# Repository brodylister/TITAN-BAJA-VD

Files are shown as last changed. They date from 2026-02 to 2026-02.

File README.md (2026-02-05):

## Baja SAE – Titan Racing Baja
Titan Racing Baja SAE is a mechanical engineering club for students to design, build and race a custom off-road vehicle for the annual collegiate competition. Designing and building a car requires us to apply engineering problems to the real world. We gain invaluable skills in design, manufacturing, and project management that prepare us for professional careers. At **CSUF**, our Baja SAE team consists of 14 members, and our goal is to compete in the BAJA SAE Competion that is in Washougal, Washington in May 2026. We are divided into four subteams:

- Chassis / Ergonomics 
- Drivetrain  
- Suspension  
- Vehicle Dynamics / Data Acquisition  

---

## Vehicle Dynamics & Data Acquisition
For the **Vehicle Dynamics / Data Acquisition (VD/DAQ)** subteam, this focuses heavily on the electrical, sensor data, and data analysis work on the car.

We currently run **8 sensors** on the Baja car, all connected to an Arduino based DAQ system to record performance data during testing and competition runs. The system logs:

- Vehicle speed  
- Distance traveled  
- Time  
- Engine RPM  
- Secondary (CVT) RPM  
- Gyroscope data (roll, pitch, yaw)  
- 3-axis acceleration  
- Brake pressure bias  

All sensor data is routed through an **Arduino and SD card reader shield**, allowing each run to be logged directly to an SD card. The recorded data is then processed and analyzed in **MATLAB** to evaluate vehicle performance, CVT behavior, braking balance, and driver inputs.

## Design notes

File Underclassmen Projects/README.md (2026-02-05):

## Underclassmen Projects (Coding)

I have a few underclassmen projects for anyone interested in writing code for **CVT tuning** and the **main DAQ harness** that will be installed on the car. These projects are a great opportunity to gain hands on experience with Arduino based data acquisition and sensor integration.

For coding related work, please reference **version 8 (v8)** of the code located in either the **CVT** or **DAQ** folders. This version should be used as the baseline for development.

If you’re interested, **reach out to Katia on Discord**, and she can answer any questions you may have and help you get started.

---

### CVT DYNO

- [ ] Add code to output **live data** onto a screen  
- [ ] Display outputs for:
  - [ ] Hall effect sensor (Primary RPM)  
  - [ ] Hall effect sensor (Secondary RPM)  
  - [ ] Hall effect sensor (Disk Brake RPM)  

---

### DAQ (On Vehicle)

- [ ] Code the **IMU (MPU-6050)** to record and send its data to the Arduino  
- [ ] Log IMU data onto an SD card using the **SD Card Reader Shield** (so it can be exported to Excel / MATLAB later)  
- [ ] IMU signals to record:
  - [ ] Angular velocity (gyro): **X, Y, Z**
  - [ ] Linear acceleration (accelerometer): **X, Y, Z**

> Note: The MPU-6050 is a 3-axis accelerometer and gyroscope. There are many examples available on GitHub and YouTube that can be used as references.

---

## Underclassmen Projects (Hands On)

For those interested in hands on work, there are opportunities to help test and validate the sensors we are using by connecting them to an Arduino and breadboard while we wait for final parts to be delivered. This is a great way to get familiar with the hardware and basic wiring before full integration.

A future project will involve assisting with **harness assembly and integration** once all components arrive, including helping connect and route the wiring for the CVT dyno and on vehicle DAQ systems. Interested students should reach out to Katia for more information.

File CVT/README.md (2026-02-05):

## CVT Dyno Harness & Tuning Overview

In addition to the vehicle DAQ system, we are developing a **separate electrical harness for the CVT dyno**. This setup is designed specifically for **CVT testing and tuning** in a controlled environment and does not require the same level of durability as the on vehicle harness.

The CVT dyno harness uses an **Arduino Uno with an SD card reader shield** to log data and display real time feedback during testing. The system includes the following components:

- Hall effect sensor – Primary RPM  
- Hall effect sensor – Secondary RPM  
- Hall effect sensor – Disk Brake RPM  
- Push button (test control / reset)  
- LED indicators (system status)  
- Real Time Clock (RTC)  
- Display screen for real time output  

The hall effect sensors allow us to measure **primary, secondary, and wheel RPM**, which are critical for understanding CVT behavior under different load and throttle conditions. Data is logged to an SD card for analysis, while the display provides immediate feedback during testing.

---

## Purpose of CVT Tuning

The purpose of CVT tuning is to optimize the transmission’s performance by ensuring the engine operates within its ideal RPM range throughout acceleration and load changes. By analyzing the relationship between **primary RPM, secondary RPM, and wheel RPM**, we can evaluate:

- Shift behavior and ratio changes  
- Belt slip and engagement consistency  
- Backshift response under load  
- Overall drivetrain efficiency  

This data approach allows us to make informed adjustments to **spring rates, flyweights, and CVT setup** rather than relying solely on trial and error. The CVT dyno harness provides a repeatable testing environment that directly supports on vehicle performance improvements.

---

## To Do List

- [x] Hall effect sensor – Primary RPM  
- [x] Hall effect sensor – Secondary RPM  
- [x] Hall effect sensor – Disk Brake RPM  
- [x] Push button (test control / reset)  
- [x] LED indicators (system status)  
- [x] Real-Time Clock (RTC)  
- [ ] Display screen for real-time output

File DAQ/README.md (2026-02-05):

## System Overview

The DAQ system is responsible for collecting sensor data during testing and competition runs, logging it to an SD card. The on vehicle DAQ system is built around an **Arduino** paired with an **SD card reader shield**. Sensor inputs are recorded during each run and saved to an SD card for later analysis. This data is used to evaluate vehicle performance, driver behavior, and drivetrain response under real off road conditions.

Power for the DAQ system is supplied by the vehicle’s **12V battery**. A **buck converter** is used to step the voltage down from **12V to 5V** for sensors and components that require regulated 5V power, ensuring stable operation and protecting sensitive electronics.

---

## Sensors & Components

### Core DAQ Hardware
- Arduino  
- SD card reader shield  
- Buck converter (12V → 5V)

### Sensors / Inputs
- Brake Pressure Sensor (BPS)  
- Hall effect sensor – Secondary RPM  
- Spark plug RPM pickup – Primary RPM  
- IMU (gyroscope + accelerometer)  
- IR sensor (temperature monitoring)  
- GPS module (position / speed tracking)  
- Real Time Clock (RTC)  
- Push button (test control / marker)  
- LED indicators (system status)

---

## Data Logging & Output

During a run, sensor signals are routed into the Arduino, time stamped using the RTC, and logged to the SD card. Data is then transferred for processing and analysis in **MATLAB**, where it can be used to evaluate:

- Vehicle speed and distance trends  
- Engine and CVT RPM behavior  
- Brake pressure bias and braking consistency  
- Vehicle dynamics (roll, pitch, yaw, and acceleration)  
- Thermal behavior from IR sensor readings  
- GPS-based track mapping and run comparison  

---

## Live Transmission

In addition to SD logging, the DAQ system supports **live transmission** to allow real time monitoring during testing without removing the SD card.

### On-Vehicle Hardware (Transmitter)
- **XBee Pro 900HP – DMST**
- XBee Xplorer shield
- Antenna

### Base Station Hardware (Receiver)
- **XBee Pro 900HP – DMUT**
- Antenna

Live telemetry is primarily used during testing sessions to monitor system health and vehicle behavior in real time.

---

## To Do List

### Code  
- [x] SD card reader shield (data logging)  
- [x] Real-Time Clock (RTC) integration  
- [ ] Brake Pressure Sensor (BPS)  
- [x] Hall effect sensor – Secondary RPM  
- [x] Spark plug RPM pickup – Primary RPM  
- [ ] IMU (gyroscope + accelerometer)  
- [ ] IR sensor (temperature monitoring)  
- [ ] GPS module  
- [x] Push button (test control / marker)  
- [x] LED indicators (system status)  

### Live Transmission (Telemetry)
- [ ] XBee Pro 900HP – DMST (on-vehicle transmitter)  
- [ ] XBee Xplorer shield  
- [ ] Antenna (vehicle side)  
- [ ] XBee Pro 900HP – DMUT (base station receiver)  
- [ ] Antenna (base station)

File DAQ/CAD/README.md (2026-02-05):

# DAQ Electrical CAD Overview

This folder contains the **CAD documentation for the on-vehicle Data Acquisition (DAQ) electrical system**, including wiring layouts, connector organization, and harness routing. The purpose of this CAD is to clearly communicate how the electrical system is physically and electrically connected, making it easier to build, troubleshoot, and modify the DAQ harness.

For circuit systems, CAD is used to:
- Visualize wiring routes and connector locations  
- Define wire types, gauges, and colors  
- Reduce wiring errors during assembly  
- Provide clear documentation for future revisions  

---

## Wire Color & Gauge Standards

The DAQ electrical system follows a consistent wire color and gauge standard to simplify identification, troubleshooting, and future modifications.

### Power & Ground
- **Red – 18 AWG**  
  - 12V power supply  

- **Black – 18 AWG**  
  - Ground (GND)  

### Low-Voltage & Logic Signals
- **Orange – 22 AWG**  
  - 5V power  

- **Pink – 22 AWG**  
  - Logic signal  

- **Dark Blue – 22 AWG**  
  - Logic signal  

### Shielded Signal
- **Green – 22 AWG**  
  - Noise-sensitive sensor signals  

---

## Live Transmission Cable Color Standards

To clearly identify live transmission connections in CAD and during assembly, the following cable color standards are used:

- **Maroon**  
  - U.FL → SMA antenna cable (base station)

- **Purple**  
  - LMR-400 coaxial cable (base station)

---

## RTC (QT / Qwiic) Cable Color Standards

The RTC connections use QT (Qwiic) cabling with the following color assignments:

- **Violet**  
  - QT → QT connection  

- **Grey**  
  - QT → external connection  

---

## Notes

Wire and cable colors are selected based on current requirements, signal sensitivity, and ease of identification. Shielded wiring is used where necessary to reduce electrical noise and improve signal reliability, especially for sensitive sensor and communication lines.

This CAD documentation serves as the primary reference for DAQ harness fabrication and should be followed during assembly, testing, and future revisions.

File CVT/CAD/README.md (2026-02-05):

# CVT Electrical CAD Overview

This folder contains the **CAD documentation for the CVT electrical system**, including wiring layouts, connector organization, and harness routing. The purpose of this CAD is to clearly communicate how the electrical system is physically and electrically connected, making it easier to build, troubleshoot, and modify the harness.

For circuit systems, CAD is used to:
- Visualize wiring routes and connector locations  
- Define wire types, gauges, and colors  
- Reduce wiring errors during assembly  
- Provide clear documentation for future revisions  

---

## Wire Color & Gauge Standards

The CVT electrical system follows a consistent wire color and gauge standard to simplify identification and troubleshooting.

### Power & Ground
- **Red – 18 AWG**  
  - 12V power supply  

- **Black – 18 AWG**  
  - Ground (GND)  

### Low-Voltage & Logic Signals
- **Orange – 22 AWG**  
  - 5V power  

- **Pink – 22 AWG**  
  - Logic signal  

- **Dark Blue – 22 AWG**  
  - Logic signal  

### Shielded Signal
- **Green – 22 AWG**  
  - Noise-sensitive sensor signals  

---

## Notes

Wire colors and gauges are selected based on current requirements, signal sensitivity, and durability. Shielded wiring is used where necessary to reduce electrical noise and improve signal reliability.

This CAD documentation serves as the reference for harness fabrication and should be followed during assembly and testing.

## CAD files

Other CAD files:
CVT/CAD/v4/CVT_DYNO_BOM_WIRE_CONNECTORS_V4_KM.dwg
DAQ/CAD/v6/DAQ_Harness_V6_KM.dwg
CVT/CAD/v4/CVT_DYNO_V4_KM.dwg
DAQ/CAD/v6/DAQ_CONNECTOR_V6_KM.dwg
DAQ/CAD/v6/DAQ_WIRE_V6_KM.dwg
DAQ/CAD/v6/DAQ_Live_Transmission_V6_KM.dwg
DAQ/CAD/v6/DAQ_IMU_ARDUINO_BOX_V6_KM.dwg
DAQ/CAD/v6/DAQ_BOM_V6_KM.dwg

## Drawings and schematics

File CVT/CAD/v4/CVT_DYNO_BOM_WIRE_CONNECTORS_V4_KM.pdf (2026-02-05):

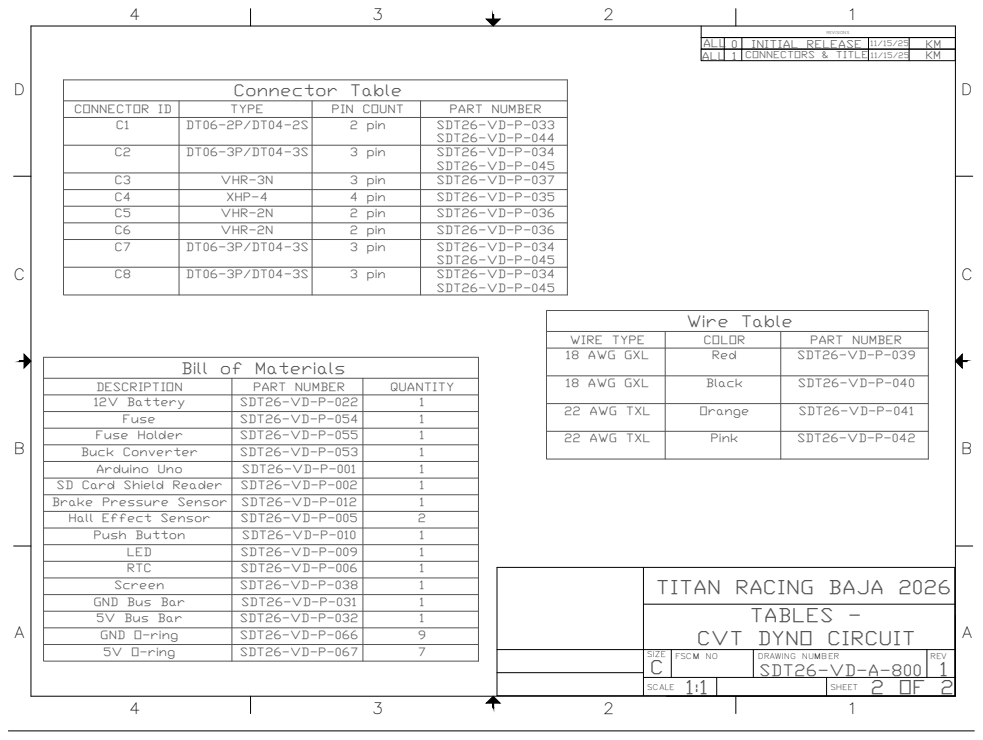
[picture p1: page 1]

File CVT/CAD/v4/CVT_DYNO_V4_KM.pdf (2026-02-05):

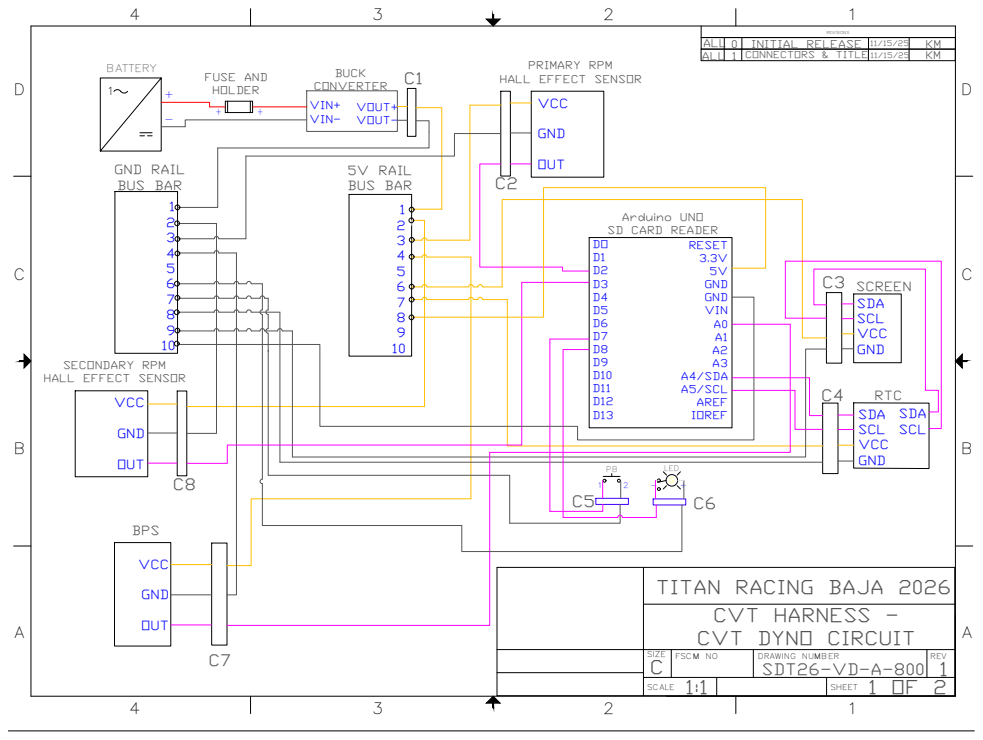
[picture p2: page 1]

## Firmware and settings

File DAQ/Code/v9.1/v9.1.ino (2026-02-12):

/*
Author: Brody Lister
Version: v9.1
System: DAQ

Description:
- Version currently works for:
  - IMU
  - SD
  - RTC (including updating time if power was lost)
- Signs of Leon's vibe coding removed

Sensors Included:
- Hall Effect (Primary & Secondary RPM) [Foundation]
- DS3231 RTC (Real Time Clock) [Foundation]
- MPU-6050 (Accelerometer & Gyroscope)
*/

#include <Wire.h>
#include <SPI.h>
#include <SD.h>
#include <RTClib.h>
#include <Adafruit_MPU6050.h>
#include <Adafruit_Sensor.h>

RTC_DS3231 rtc;
Adafruit_MPU6050 mpu;


// -------- Pins --------
const int SD_CS        = 10;
const int hallPrimary  = 2;
const int hallSecondary = 3;
const int ledPin       = 8;
const int buttonPin    = 7;

// -------- Settings --------
const unsigned long SAMPLE_MS   = 50;  // 20Hz Sampling
const uint8_t       PPR         = 1;   // Pulses Per Rev
const unsigned long DEBOUNCE_MS = 50;  

// -------- Counters / State --------
volatile unsigned long cntP = 0, cntS = 0;

bool logging     = false;
bool lastStable  = HIGH; 
bool debouncing  = false;
unsigned long tDebounce = 0;

bool sdOk  = false;
bool rtcOk = false;
bool mpuOk = false;

unsigned long t0_ms = 0; 
char filename[16]; 

// --- ISRs ---
void isrP() { cntP++; }
void isrS() { cntS++; }

// --- Build File Name ---
void buildNewRunFilename() {
  int run = 1;
  do {
    // 8.3 format: RUN001.CSV
    sprintf(filename, "RUN%03d.CSV", run); 
    run++;
  } while (SD.exists(filename));
}

// --- Write Header ---
void writeHeader() {
  File localFile = SD.open(filename, FILE_WRITE);
  if (localFile) {

    if (rtcOk) {
      localFile.println(F("Date,Time,P_RPM,S_RPM,AccX,AccY,AccZ,GyroX,GyroY,GyroZ"));
    } else {
      localFile.println(F("Time_s,P_RPM,S_RPM,AccX,AccY,AccZ,GyroX,GyroY,GyroZ"));
    }
    
    localFile.close();
    Serial.println(F("Header written"));
  } else {
    Serial.println(F("Header write fail"));
  }
}

void setup() {
  Serial.begin(9600);
  Wire.begin();

  pinMode(ledPin, OUTPUT);
  digitalWrite(ledPin, LOW);
  pinMode(buttonPin, INPUT_PULLUP);
  pinMode(hallPrimary, INPUT_PULLUP);
  pinMode(hallSecondary, INPUT_PULLUP);

  attachInterrupt(digitalPinToInterrupt(hallPrimary), isrP, FALLING);
  attachInterrupt(digitalPinToInterrupt(hallSecondary), isrS, FALLING);

  Serial.println(F("Initializing DAQ v9..."));

  // --- SD ---
  sdOk = SD.begin(SD_CS);
  Serial.print(F("SD: ")); Serial.println(sdOk ? F("OK") : F("FAIL"));

  // --- RTC ---
  rtcOk = rtc.begin();
  Serial.print(F("RTC: ")); Serial.println(rtcOk ? F("OK") : F("FAIL"));

  // [NEW] >>> rtcOk reads false at compile-time. Just check if rtc.lostPower() to adjust clock.
  if (rtc.lostPower()) {
    rtc.adjust(DateTime(F(__DATE__), F(__TIME__)));
  }

  // Try to find MPU at address 0x69 first (AD0 = HIGH) to avoid RTC conflict
  if (!mpu.begin(0x69)) {
    Serial.println(F("MPU6050 not found at 0x69! Check AD0 pin (Connect to 3.3V)."));
    mpuOk = false;
  } else {
    Serial.println(F("MPU6050 OK at 0x69"));
    mpuOk = true;
    
    // Configure settings for Baja vehicle dynamics
    mpu.setAccelerometerRange(MPU6050_RANGE_8_G); // 8G range (Bumps are >2G)
    mpu.setGyroRange(MPU6050_RANGE_500_DEG);      // Standard rotation speed
    mpu.setFilterBandwidth(MPU6050_BAND_21_HZ);   // Low pass filter (removes engine vibration)
  }


  t0_ms = millis();
  Serial.println(F("Ready. Press Btn."));
}

void loop() {
  unsigned long nowMs = millis();

// --- Button Logic (Toggle) ---
  bool raw = digitalRead(buttonPin);
  if (!debouncing && raw != lastStable) {
    debouncing = true;
    tDebounce = nowMs;
  }
  if (debouncing && (nowMs - tDebounce) > DEBOUNCE_MS) {
    bool raw2 = digitalRead(buttonPin);
    if (raw2 != lastStable) {
      
      // BUTTON RELEASED -> TOGGLE LOGGING
      if (lastStable == LOW && raw2 == HIGH) { 
        if (!logging) {
          // --- START LOGGING ---
          
          // FIX: Force SD card restart every time, which should allow ability to swap cards without resetting the Arduino.
          sdOk = SD.begin(SD_CS); 
          
          if (sdOk) {
            buildNewRunFilename(); // Scans card and finds next available number
            writeHeader();
            logging = true;
            digitalWrite(ledPin, HIGH);
            Serial.print(F("LOG ON -> ")); Serial.println(filename);
          } else {
            // If card is missing or broken
            Serial.println(F("SD Error - Insert Card"));
            // Blink LED as an indicator
            for(int i=0; i<5; i++) { 
              digitalWrite(ledPin, HIGH); delay(50); 
              digitalWrite(ledPin, LOW); delay(50); 
            }
          }
        } else {
          // --- STOP LOGGING ---
          logging = false;
          digitalWrite(ledPin, LOW);
          Serial.println(F("LOG OFF"));
        }
      }
      lastStable = raw2;
    }
    debouncing = false;
  }

  // --- Sampling Loop ---
  static unsigned long lastSample = 0;
  if (logging && (nowMs - lastSample >= SAMPLE_MS)) {
    lastSample = nowMs;

    // 1. Grab RPM Counts (Foundation)
    noInterrupts();
    unsigned long nP = cntP;
    unsigned long nS = cntS;
    cntP = 0; cntS = 0;
    interrupts();

    // READ SENSOR EVENTS
    sensors_event_t a, g, temp;
    if (mpuOk) {
      mpu.getEvent(&a, &g, &temp);
    }


    // 3. Calculation (Foundation)
    float rpmP = (nP * (60000.0 / SAMPLE_MS)) / PPR;
    float rpmS = (nS * (60000.0 / SAMPLE_MS)) / PPR;

    // 4. Write to SD
    File localFile = SD.open(filename, FILE_WRITE);
    if (localFile) {
      // Time (Foundation)
      if (rtcOk) {
        DateTime dt = rtc.now();
        localFile.print(dt.year()); localFile.print('/');
        localFile.print(dt.month()); localFile.print('/');
        localFile.print(dt.day()); localFile.print(',');
        localFile.print(dt.hour()); localFile.print(':');
        localFile.print(dt.minute()); localFile.print(':');
        localFile.print(dt.second()); localFile.print(',');
      } else {
        localFile.print((millis() - t0_ms) / 1000.0, 3);
        localFile.print(',');
      }

      // RPM (Foundation)
      localFile.print(rpmP, 0); localFile.print(',');
      localFile.print(rpmS, 0); localFile.print(',');

      // WRITE IMU DATA TO SD
      if (mpuOk) {
        // Accelerometer (X, Y, Z)
        localFile.print(a.acceleration.x, 2); localFile.print(',');
        localFile.print(a.acceleration.y, 2); localFile.print(',');
        localFile.print(a.acceleration.z, 2); localFile.print(',');
        // Gyroscope (X, Y, Z)
        localFile.print(g.gyro.x, 2); localFile.print(',');
        localFile.print(g.gyro.y, 2); localFile.print(',');
        localFile.println(g.gyro.z, 2); // println ends the CSV row
      } else {
        // Fill with zeros if sensor failed so CSV columns don't break
        localFile.println(F("0,0,0,0,0,0")); 
      }


      localFile.close();
    } else {
      Serial.println(F("File Open Fail"));
    }
  }
}

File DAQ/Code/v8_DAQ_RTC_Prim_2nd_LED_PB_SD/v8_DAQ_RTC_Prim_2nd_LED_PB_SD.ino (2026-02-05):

// CSUF BAJA SAE – VD/DAQ (Simple Version)
// Logs Primary & Secondary RPM with RTC time/date to SD.
// Button D7<->GND toggles logging (INPUT_PULLUP). LED D8 ON while logging.
// SD CS=D10. Hall sensors on D2/D3. RTC uses A4(SDA)/A5(SCL).

#include <Wire.h>
#include <RTClib.h>
#include <SPI.h>
#include <SD.h>

RTC_DS3231 rtc;

// -------- Pins --------
const int SD_CS        = 10;
const int hallPrimary  = 2;
const int hallSecondary = 3;
const int ledPin       = 8;
const int buttonPin    = 7;

// -------- Settings --------
const unsigned long SAMPLE_MS   = 50;  // sample window in ms
const uint8_t       PPR         = 1;    // pulses per rev (magnets per rev)
const unsigned long DEBOUNCE_MS = 50;   // button debounce

// -------- Counters / State --------
volatile unsigned long cntP = 0, cntS = 0;

bool logging     = false;
bool lastStable  = HIGH;   // button idle (INPUT_PULLUP)
bool debouncing  = false;
unsigned long tDebounce = 0;

bool sdOk  = false;
bool rtcOk = false;
unsigned long t0_ms = 0;   // millis at power-up (for fallback time)
char filename[32];

// --- ISRs (Hall Sensors) ---
void isrP() {
  cntP++;
}
void isrS() {
  cntS++;
}

// --- Build new file name ---
// Use simple 8.3 format: RUN001.CSV, RUN002.CSV, etc.
void buildNewRunFilename() {
  int run = 1;
  do {
    snprintf(filename, sizeof(filename), "RUN%03d.CSV", run);  // RUN001.CSV
    run++;
  } while (SD.exists(filename));
}

// --- Write CSV header row ---
void writeHeader() {
  File localFile = SD.open(filename, FILE_WRITE);
  if (localFile) {
    if (rtcOk) {
      localFile.println("Date,Time,Primary_RPM,Secondary_RPM");
    } else {
      localFile.println("Time_s,Primary_RPM,Secondary_RPM");
    }
    localFile.close();
    Serial.println("✅ Header written");
  } else {
    Serial.println("❌ Header write failed (open)");
  }
}

void setup() {
  Serial.begin(9600);
  Wire.begin();

  pinMode(ledPin, OUTPUT);
  digitalWrite(ledPin, LOW);

  pinMode(buttonPin, INPUT_PULLUP);
  pinMode(hallPrimary, INPUT_PULLUP);
  pinMode(hallSecondary, INPUT_PULLUP);

  attachInterrupt(digitalPinToInterrupt(hallPrimary), isrP, FALLING);
  attachInterrupt(digitalPinToInterrupt(hallSecondary), isrS, FALLING);

  Serial.println("Initializing DAQ...");

  // --- SD card ---
  sdOk = SD.begin(SD_CS);
  Serial.print("SD: ");
  Serial.println(sdOk ? "OK" : "FAIL");

  // --- RTC ---
  rtcOk = rtc.begin();
  Serial.print("RTC: ");
  Serial.println(rtcOk ? "OK" : "FAIL");

  /* initial commit so RTC has accurate time, this forces the RTC to reset with the computer everytime upload code
  
  if (rtcOk) {
  Serial.println("Setting RTC to compile time");
  rtc.adjust(DateTime(F(__DATE__), F(__TIME__)));
} 

  */

  // only resets the RTC time  if the battery dies or it loses power
  if (rtcOk && rtc.lostPower()) {
  Serial.println("RTC lostPower -> setting compile time");
  rtc.adjust(DateTime(F(__DATE__), F(__TIME__)));
}

  t0_ms = millis();
  Serial.println("DAQ ready. Press button to START/STOP logging.");
}

void loop() {
  unsigned long nowMs = millis();

  // --- Debounced pushbutton toggle (on RELEASE) ---
  bool raw = digitalRead(buttonPin);  // HIGH idle, LOW pressed
  if (!debouncing && raw != lastStable) {
    debouncing = true;
    tDebounce = nowMs;
  }
  if (debouncing && (nowMs - tDebounce) > DEBOUNCE_MS) {
    bool raw2 = digitalRead(buttonPin);
    if (raw2 != lastStable) {
      // toggle on release: LOW -> HIGH
      if (lastStable == LOW && raw2 == HIGH) {
        if (!logging) {
          // Turning logging ON
          if (!sdOk) {
            sdOk = SD.begin(SD_CS);
            Serial.print("Retry SD: ");
            Serial.println(sdOk ? "OK" : "FAIL");
          }
          if (sdOk) {
            buildNewRunFilename();
            writeHeader();
            logging = true;
            digitalWrite(ledPin, HIGH);
            Serial.print("▶ LOG ON -> ");
            Serial.println(filename);
          } else {
            Serial.println("⛔ Cannot start logging (SD not OK).");
          }
        } else {
          // Turning logging OFF
          logging = false;
          digitalWrite(ledPin, LOW);
          Serial.println("■ LOG OFF");
        }
      }
      lastStable = raw2;
    }
    debouncing = false;
  }

  // --- Periodic sample & write ---
  static unsigned long lastSample = 0;
  if (logging && (nowMs - lastSample >= SAMPLE_MS)) {
    lastSample = nowMs;

    // Copy and reset counts safely
    noInterrupts();
    unsigned long nP = cntP;
    unsigned long nS = cntS;
    cntP = 0;
    cntS = 0;
    interrupts();

    // RPM calculations
    float rpmP = (nP * (60000.0 / SAMPLE_MS)) / PPR;
    float rpmS = (nS * (60000.0 / SAMPLE_MS)) / PPR;

    File localFile = SD.open(filename, FILE_WRITE);
    if (localFile) {
      // --- Time/Date Column(s) ---
      if (rtcOk) {
        DateTime dt = rtc.now();
        // Date: YYYY/MM/DD
        localFile.print(dt.year());
        localFile.print('/');
        if (dt.month() < 10) localFile.print('0');
        localFile.print(dt.month());
        localFile.print('/');
        if (dt.day() < 10) localFile.print('0');
        localFile.print(dt.day());
        localFile.print(',');

        // Time: HH:MM:SS
        if (dt.hour() < 10) localFile.print('0');
        localFile.print(dt.hour());
        localFile.print(':');
        if (dt.minute() < 10) localFile.print('0');
        localFile.print(dt.minute());
        localFile.print(':');
        if (dt.second() < 10) localFile.print('0');
        localFile.print(dt.second());
        localFile.print(',');
      } else {
        // Fallback: time since power-up (seconds)
        float tsec = (millis() - t0_ms) / 1000.0;
        localFile.print(tsec, 3);
        localFile.print(',');
      }

      // --- RPM Data Columns ---
      localFile.print(rpmP, 2);
      localFile.print(',');
      localFile.println(rpmS, 2);

      localFile.close();
      Serial.println("💾 write ok");
    } else {
      Serial.println("❌ file open fail");
    }
  }
}

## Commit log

2026-02-04 Create CAD
2026-02-05 Enhance README with system overview and components
    Added detailed system overview, sensors, data logging, live transmission, and to-do list sections to the README.
2026-02-05 Add CAD documentation for CVT electrical system
    Added detailed CAD documentation for the CVT electrical system, including wiring layouts, standards, and notes for assembly.
2026-02-05 Add .gitkeep to CVT/CAD/V1 directory
2026-02-05 Create README.md for DAQ Electrical CAD documentation
    Added comprehensive CAD documentation for the DAQ electrical system, including wire color standards and cable specifications.
2026-02-11 progess in 12v rail addition
    question marks need removed in WIRE and BOM and CONNECTOR.
    HARNESS and CONNECTOR wip.
    [DAQ_BOM_V6_KM.dwg, DAQ_CONNECTOR_V6_KM.dwg, DAQ_Harness_V6_KM.dwg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]
2026-02-12 v9.1 working with rtc, imu, sd
